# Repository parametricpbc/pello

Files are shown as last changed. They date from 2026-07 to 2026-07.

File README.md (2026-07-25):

# Pello — Parametric's open-source GELLO leader arms

Open-source bimanual [GELLO](https://wuphilipp.github.io/gello_site/) teleoperation leader
arms, purpose-built to drive **[i2rt YAM](https://github.com/i2rt-robotics) follower arms**.
Each leader is a **5/8-scale replica of the 6-DOF YAM** (plus a gripper trigger), sensed by
**7× Feetech STS3215 serial-bus servos per arm**. You move the lightweight leaders by hand
and the YAM followers mirror your motion in real time via
[LeRobot](https://github.com/huggingface/lerobot).

> **Designed for the 6-DOF YAM**, not the 5-DOF SO-100. The software happens to drive the
> YAM through LeRobot's SO-100 follower interface, but the arm geometry and joint count are
> the YAM's.

<!-- TODO(preliminary): add a hero photo / short GIF of the arms in use -->

## What's in this repo

| Path | Contents |
|---|---|
| [`hardware/`](hardware/) | Bill of materials, 3D-print file, and assembly instructions |
| [`Uarm_teleop/Feetech_servo/`](Uarm_teleop/Feetech_servo/) | Servo GUI, bus scanner, and ID-assignment tools |
| [`Follower_Arm/LeRobot/`](Follower_Arm/LeRobot/) | Drive an i2rt YAM follower from the leaders via LeRobot |

## Build a set

1. **Order the parts** — [`hardware/BOM.md`](hardware/BOM.md) (~$389 for a bimanual set, 14 servos).
2. **Print the frame** — [`hardware/print/gello3dp.3mf`](hardware/print/gello3dp.3mf) (one arm on each plate).
3. **Assemble** — follow [`hardware/README.md`](hardware/README.md).
4. **Bring up the software** — below.

## Quick start (software)

**1. Install dependencies**

```bash
pip install -r requirements.txt
```

**2. Set your serial ports.** Each USB adapter enumerates differently per machine:

```bash
ls /dev/cu.usbmodem*   # macOS
ls /dev/ttyUSB*        # Linux
```

Update the port strings in `Uarm_teleop/Feetech_servo/feetech_gui.py` (top of file) and
`Follower_Arm/LeRobot/so100/dual_uarm_yam_teleop.py`.

**3. Assign servo IDs** (fresh servos all ship with the same default ID). With **one servo
connected to the bus at a time**, assign each an ID from **0 (base) to 6 (gripper/trigger)**:

```bash
cd Uarm_teleop/Feetech_servo
python3 feetech_servo_changeid.py 0   # then 1, 2, … 6, one servo at a time
```

The write broadcasts to every powered servo on the bus, so isolate each servo before
setting its ID. Once all 7 are set, wire the full daisy chain.

**4. Launch the servo GUI** (live 3D monitor — start here to verify a new build):

```bash
python3 feetech_gui.py
```

It opens `feetech_gui.html` in your browser, auto-discovers the servos, auto-zeros on the
first frame, and renders both arms in 3D. Press **H** to re-zero to the current pose. You
can also confirm the bus with `python3 feetech_scan.py`.

**5. Drive the YAM followers** (bimanual — each arm driven through LeRobot's SO-100 follower
interface):

```bash
cd ../../Follower_Arm/LeRobot/so100
python3 dual_uarm_yam_teleop.py
```

See [`Follower_Arm/LeRobot/README.md`](Follower_Arm/LeRobot/README.md) for the LeRobot setup.

## Hardware notes

- **Passive by design:** the two internal reduction gears are removed from each servo during
  assembly, so the joints are freely back-drivable. The servos sense position; they don't
  drive the arm (there is no active gravity compensation).
- **Servo IDs:** 0–6 per arm, stored in each servo's EEPROM. Re-assign with
  `Uarm_teleop/Feetech_servo/feetech_servo_changeid.py`.
- **Zero calibration:** captured live at startup — put the arms in their home pose before
  starting, or press **H** in the GUI to re-zero.

## Credits & license

Licensed under the **Apache License 2.0** — see [`LICENSE`](LICENSE) and [`NOTICE`](NOTICE).
This project is derived from
[MINT-SJTU/LeRobot-Anything-U-Arm](https://github.com/MINT-SJTU/LeRobot-Anything-U-Arm)
(please cite [arXiv:2509.02437](https://arxiv.org/abs/2509.02437)) and builds on the
[GELLO](https://github.com/wuphilipp/gello_mechanical) leader-arm concept (Wu et al.).

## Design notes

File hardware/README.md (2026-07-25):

# Hardware

Everything needed to build a set of Pello leader arms: bill of materials, the 3D-print
file, and assembly instructions. A set is **2 arms**, each with **7× Feetech STS3215**
servos (14 total) arranged as linkages **L1–L5** plus a **handle**, **trigger**, and
**base**.

## Bill of materials

See [`BOM.md`](BOM.md) — real parts, quantities, and prices (~$389 for a bimanual set).
The dominant cost is the 14 servos, ordered as two 6-packs plus one 2-pack.

## 3D printing

Print [`print/gello3dp.3mf`](print/gello3dp.3mf) — the master print file, one arm's parts
per plate (two plates for a bimanual set). Printed in **PETG**. This covers all structural
parts: base, L1–L5 linkages, handle, trigger, and hardstops.

Individual part STLs are in [`print/stl/`](print/stl/) (`Base`, `Home`, `L1`–`L5`, and
left/right `Handle` + `Trigger`) if you'd rather arrange your own plates or remix a
single part.

## Assembly

> The full illustrated step-by-step — with photos for every group — is in
> **[`ASSEMBLY.md`](assembly/ASSEMBLY.md)**. The outline below is a summary and follows
> that SOP's numbering. Recommend an electric screwdriver; two screw sizes are referred to
> as **BIG** and **SMALL**.

- **Step 0 — Prep the servos (×7 per arm).** Open each servo, remove the two internal
  reduction gears (this decouples the motor from the drive shaft so the joint is freely back-drivable), reassemble, and mount both servo horns (toothed + non-toothed).
- **Step 1 — Build the four sub-assemblies:** Group 1 (L1–L3), Group 2 (L4–L5), Group 3
  (handle + trigger), Group 4 (base + driver board).
- **Step 2 — Join the groups** into a full arm, then press-fit the assembly into the base (do this after
  wiring for easier cable routing).
- **Step 3 — Wire** the servos as a daisy chain terminating at the driver board, then connect
  the board to the host over USB-C.
- **Step 4 — Verify** in software: power the board, assign servo IDs, and confirm
  the bus (see bring-up below).

## Electronics & bring-up

- **Power:** ~7.4V @ 5A external DC to the servo driver board.
- **Host:** USB-C from the board to your computer.
- **Assign servo IDs first** — fresh servos all ship with the same default ID. Assign each
  an ID from **0 (base) to 6 (gripper/trigger)** with
  [`../Uarm_teleop/Feetech_servo/feetech_servo_changeid.py`](../Uarm_teleop/Feetech_servo/feetech_servo_changeid.py),
  isolating one servo on the bus at a time (the write broadcasts to every powered servo).
- **Verify the bus** — once all 7 are set and the chain is wired, run
  [`feetech_gui.py`](../Uarm_teleop/Feetech_servo/feetech_gui.py) or
  [`feetech_scan.py`](../Uarm_teleop/Feetech_servo/feetech_scan.py) and confirm IDs 0–6 all
  respond with none on the factory default.

> **Tip — steady the leaders while driving.** You move the arms by hand, so anchor each base
> so it doesn't shift mid-motion: clamp it to your table edge (a small spring or bar clamp
> works well), or even to a chair armrest for a seated teleop setup.

Full software setup is in the [top-level README](../README.md).

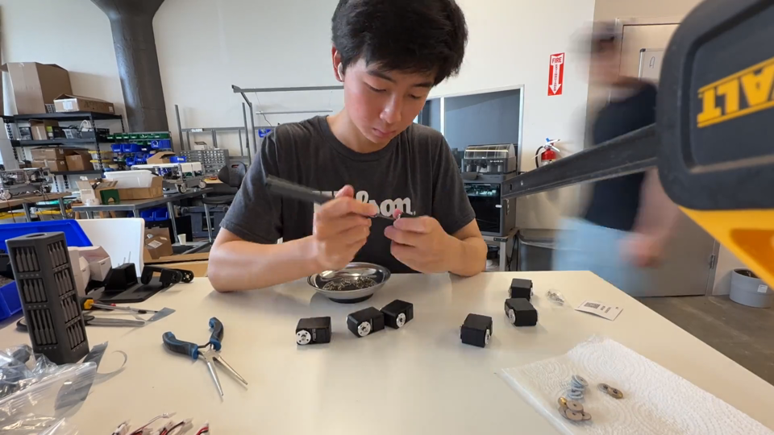
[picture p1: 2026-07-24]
hardware/assembly/img/video-poster.png

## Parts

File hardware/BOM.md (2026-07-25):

# GELLO — Bill of Materials

Everything needed to build **one set of leaders (2 arms)**: a 5/8-scale i2rt YAM
replica with **7× Feetech STS3215 servos per arm (14 total)** and a GELLO-style
gripper handle.

Prices are in USD (parts as of July 2026). The 14 servos are ordered as **two 6-packs
plus one 2-pack** — cheaper and more reliable than buying singles.

## Purchased parts

| # | Component | Qty | Price |
|---|---|----:|---:|
| 1 | [Feetech STS3215 servo — 6-pack](https://www.amazon.com/dp/B0FQHCV9GP) | 2 packs (12 servos) | $269.98 |
| 2 | [Feetech STS3215 servo — 2-pack](https://www.amazon.com/STS3215-Serial-Magnetic-Programmable-Robotic/dp/B0FVS63YNN) | 1 pack (2 servos) | $45.98 |
| 3 | [Serial bus servo driver board — Waveshare, 2-pack](https://www.amazon.com/dp/B0DK79JNNK) | 1 pack (2 boards) | $19.99 |
| 4 | [Power supply — SHNITPWR 60W universal adjustable](https://www.amazon.com/SHNITPWR-Universal-Adjustable-100V-240V-Converter/dp/B08BL55LMB) | 2 power supplies | $37.98 |
| | **Total (one leader set / 2 arms)** | | **$373.93** |

> **Not included in the total:** the **3D-printed parts** (~800 g PETG, ~$14 in filament —
> print your own or use a service; see [`print/`](print/)) and the **shared consumables**
> below.

**Servo count:** 14 total = 2 arms × 7 servos (IDs 0–6 per arm). Two 6-packs + one 2-pack =
14, with zero spare. A single-arm build needs 7 servos (one 6-pack + one 2-pack).

## Also required (not in the total)

Commodity items needed to build and run a set, but left out of the cost above.

### Consumables

Used up or installed into the build.

| Item | Qty | For |
|---|-----|-----|
| Super glue | 1 | Gluing the hardstop home onto M1 (Step 2); optionally mounting the board (see below). |
| Heat-set inserts — M2.5 | 8 (4 per arm) | Mounting the driver board to the base. The board ships with its mounting screws preinstalled, so no extra bolts are needed. |
| Rubber band — sturdy ~[#32](https://www.amazon.com/Alliance-26324-Advantage-Contains-Approx/dp/B00A27PFOC) | 2 (1 per arm) | Trigger return spring. Only a couple needed per set. |

> **No soldering iron?** You can skip the heat-set inserts entirely and **glue the
> driver board onto the back of the base** instead, mounting it the same way shown in the
> assembly reference photos. See [`ASSEMBLY.md`](assembly/ASSEMBLY.md) (Step 1, Group 4).

### Tools & other items

Reusable — not consumed and not part of the finished arm.

| Item | Qty | For |
|---|-----|-----|
| Philips screwdriver (electric recommended) | 1 | Driving all the BIG/SMALL screws; also pushing wires into the servo sockets. |
| Pliers | 1 | Freeing the servo top plates in Step 0. |
| Soldering iron | 1 | Installing the M2.5 heat-set inserts — **only if** you use inserts; skip it if you glue the board on instead. |
| USB-C cable | 2 (1 per arm) | Driver board → host computer. Any data-capable cable. |

<!-- Provenance: internal GELLO BOM (Notion) 3a6b7cb7-364f-8033-8293-d405878abf79 -->

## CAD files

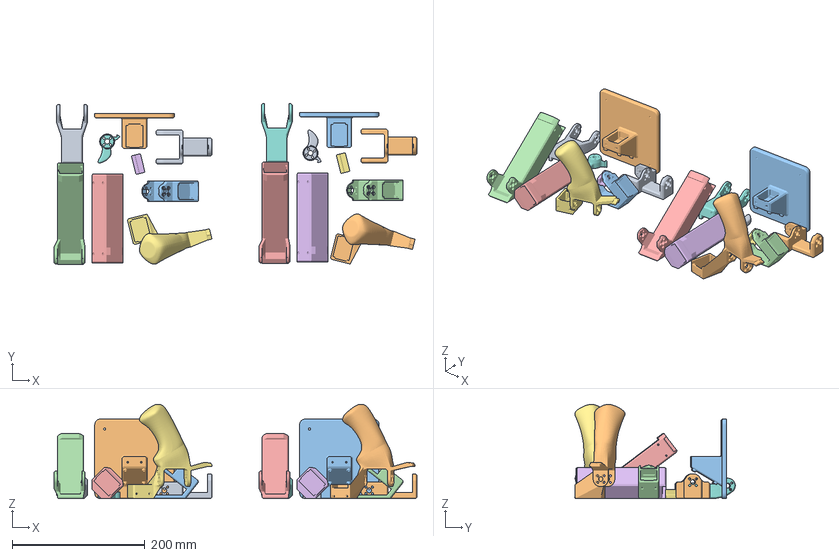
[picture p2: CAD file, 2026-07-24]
hardware/print/gello3dp.3mf
547.0 x 242.1 x 142.1 mm
L1 (1).stl x 2
Base (1).stl x 2
Current L5 (1).stl x 2
L3.stl x 2
L2 3D Model.stl x 2
Hardstop Home (4).stl x 2
Hardstop Handle (12).stl
Trigger (1).stl
Current L4 (1).stl x 2
Trigger (2).stl
Hardstop Handle (13).stl

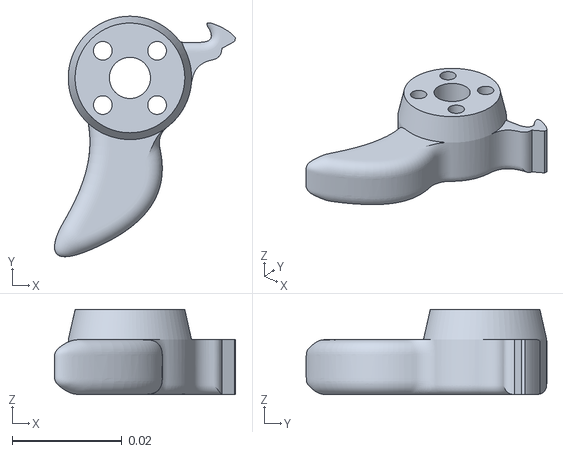
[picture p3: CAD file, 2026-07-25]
hardware/print/stl/RH Trigger.stl
0.033 x 0.0439 x 0.0155

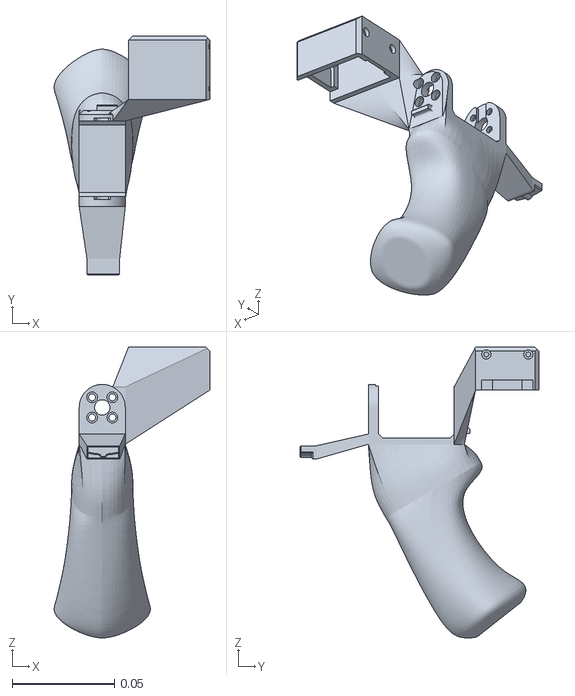
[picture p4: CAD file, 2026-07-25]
hardware/print/stl/LH Handle.stl
0.0762 x 0.117 x 0.142

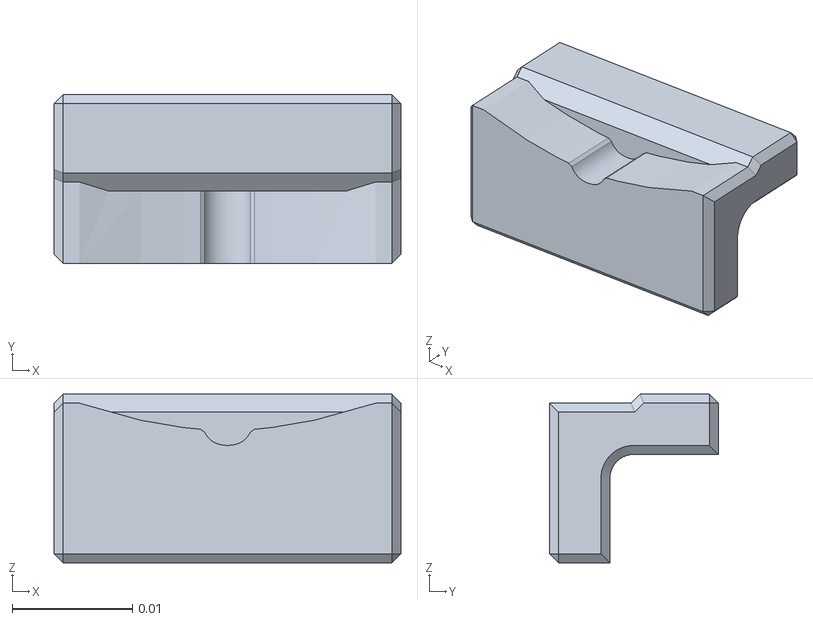
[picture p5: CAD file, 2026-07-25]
hardware/print/stl/Home.stl
0.0288 x 0.014 x 0.014

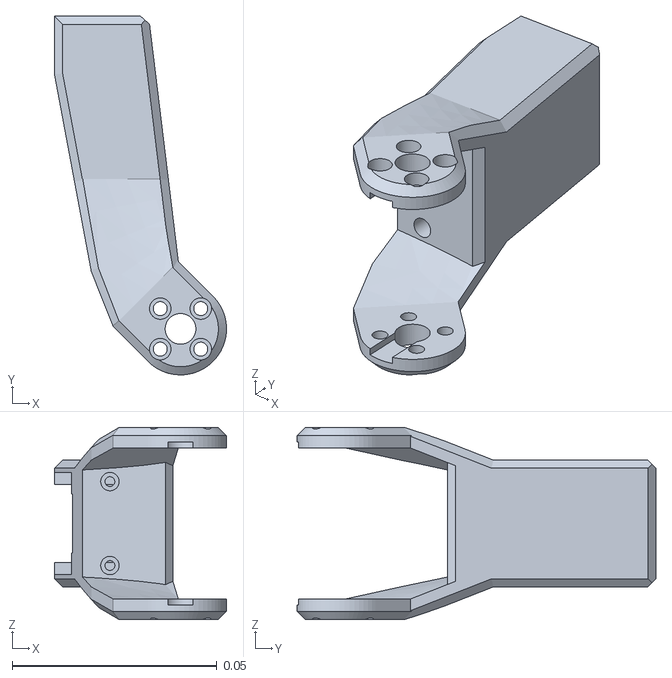
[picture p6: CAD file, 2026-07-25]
hardware/print/stl/L4.stl
0.042 x 0.0876 x 0.0469

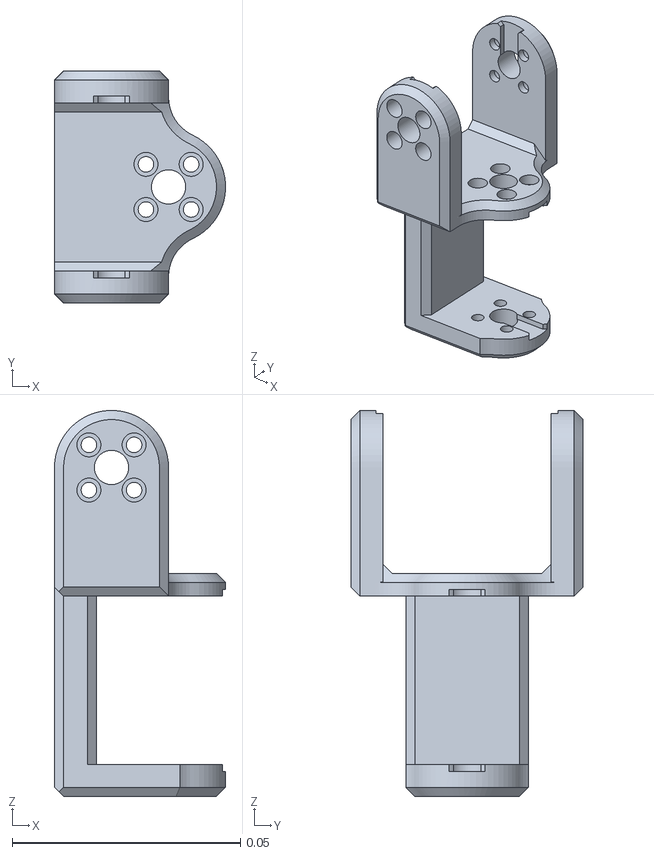
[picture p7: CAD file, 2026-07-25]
hardware/print/stl/L1.stl
0.0375 x 0.0509 x 0.0846

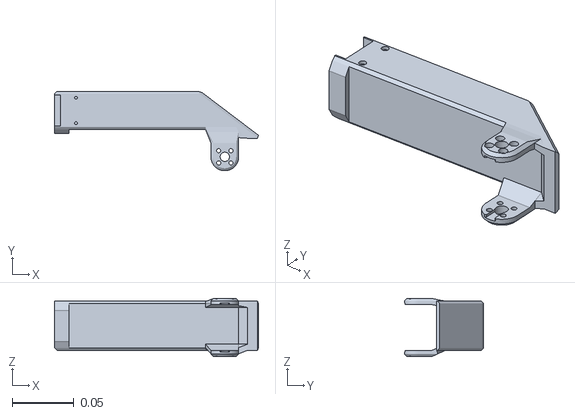
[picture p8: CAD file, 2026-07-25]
hardware/print/stl/L3.stl
0.165 x 0.0642 x 0.0469

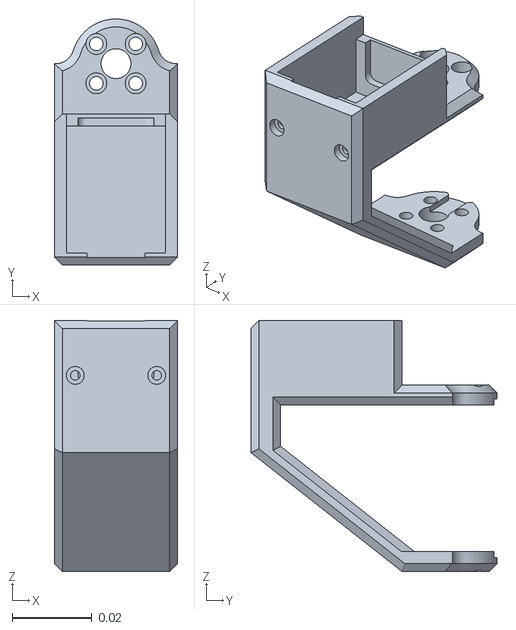
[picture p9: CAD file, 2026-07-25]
hardware/print/stl/L5.stl
0.031 x 0.0619 x 0.0632

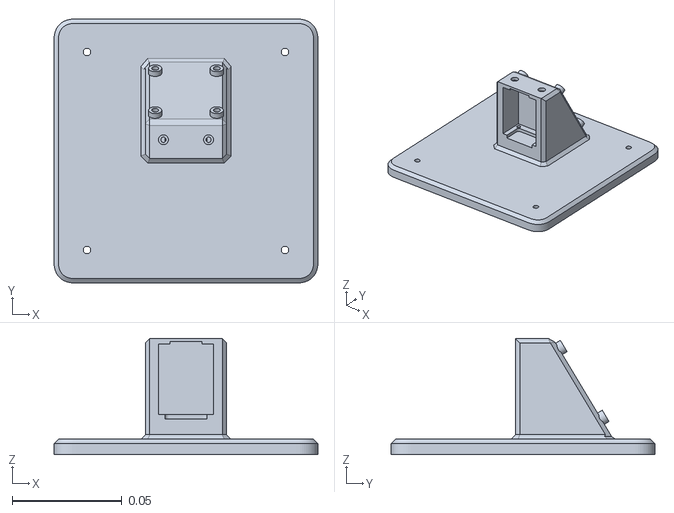
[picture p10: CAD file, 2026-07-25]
hardware/print/stl/Base.stl
0.12 x 0.12 x 0.0527

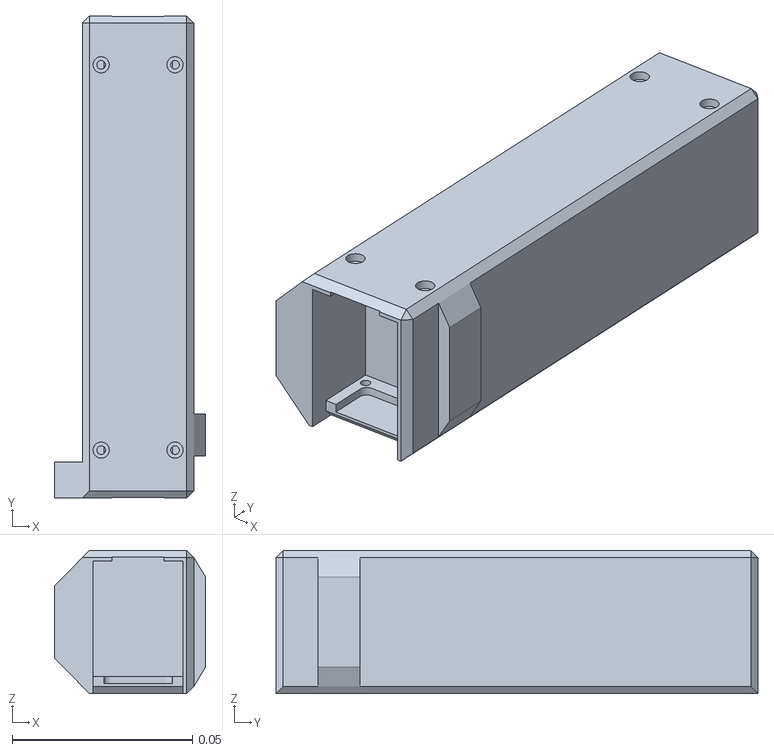
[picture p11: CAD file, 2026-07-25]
hardware/print/stl/L2.stl
0.042 x 0.134 x 0.0398

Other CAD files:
hardware/print/stl/RH Handle.stl
hardware/print/stl/LH Trigger.stl

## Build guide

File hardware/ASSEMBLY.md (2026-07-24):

# GELLO Assembly Instructions

Assembly SOP for the Parametric GELLO leader arms. Apply each step to **every one of the 7
servos / for each arm** you're building. An electric screwdriver is recommended. Two screw
sizes are referenced throughout as **BIG** and **SMALL** (both take the Philips bit).

## Video

https://github.com/user-attachments/assets/be1396df-c70d-4008-bce5-4e55a3319c4a

## Reference files

- **3D-print file:** [`gello3dp.3mf`](gello3dp.3mf)
- **Bill of materials:** [`BOM.md`](BOM.md)

## Overview

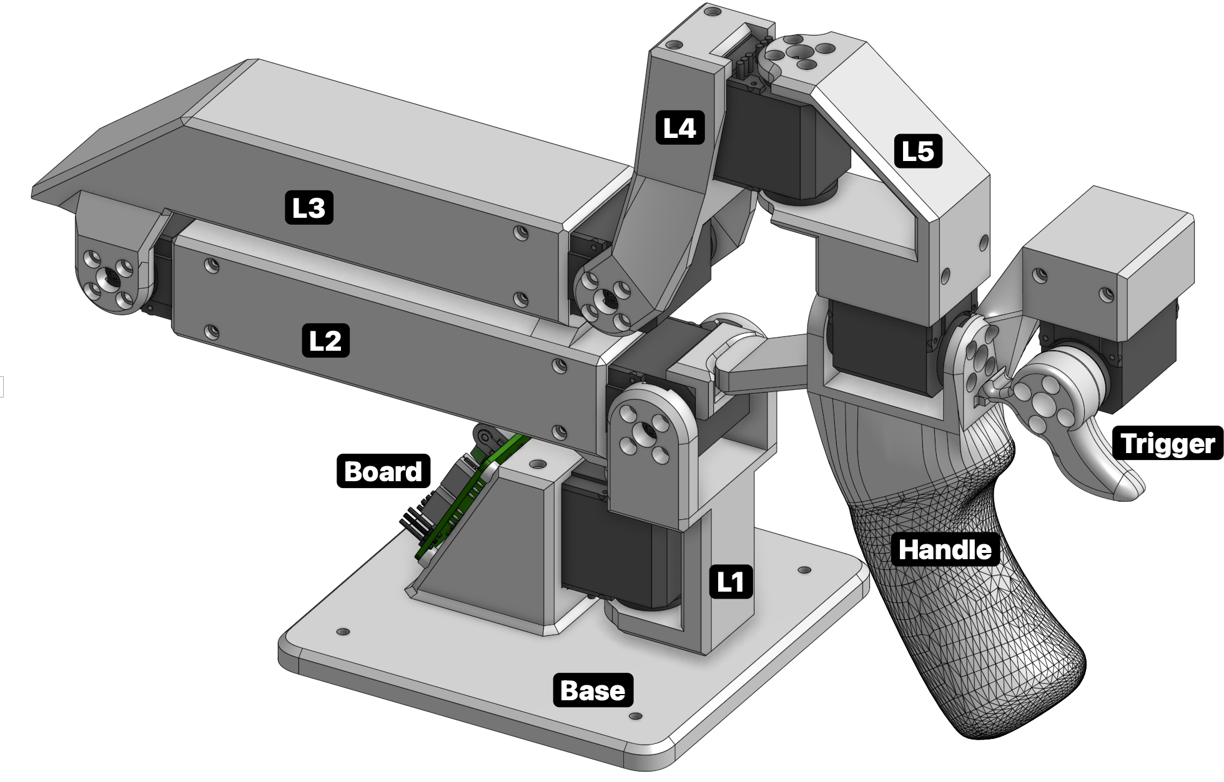
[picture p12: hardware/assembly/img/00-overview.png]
Assembly overview


Each arm builds up as four sub-assemblies:

| Group | Parts | |
|---|---|---|
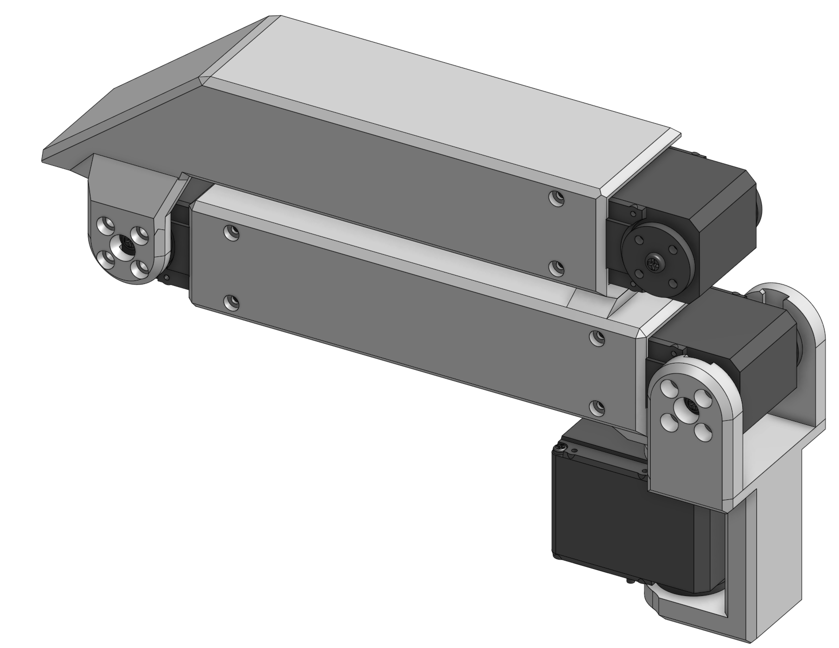
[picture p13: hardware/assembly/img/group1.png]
Group 1
| **Group 1** | L1, L2, L3 |  |
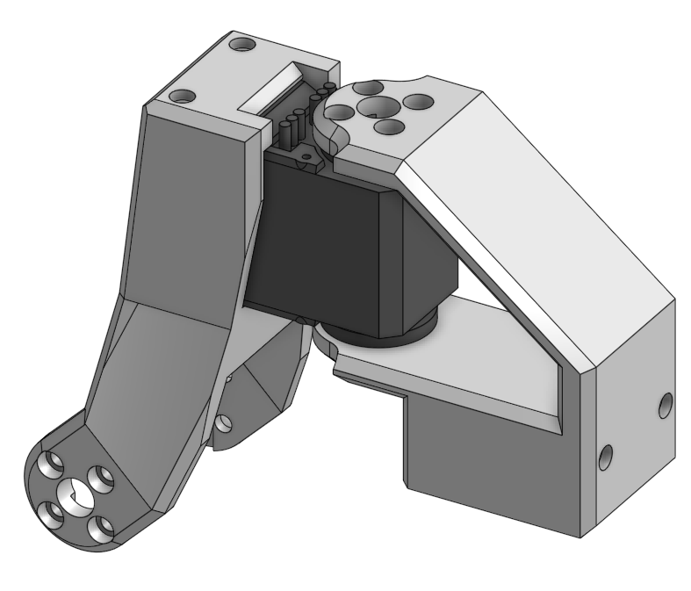
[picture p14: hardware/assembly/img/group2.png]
Group 2
| **Group 2** | L4, L5 |  |
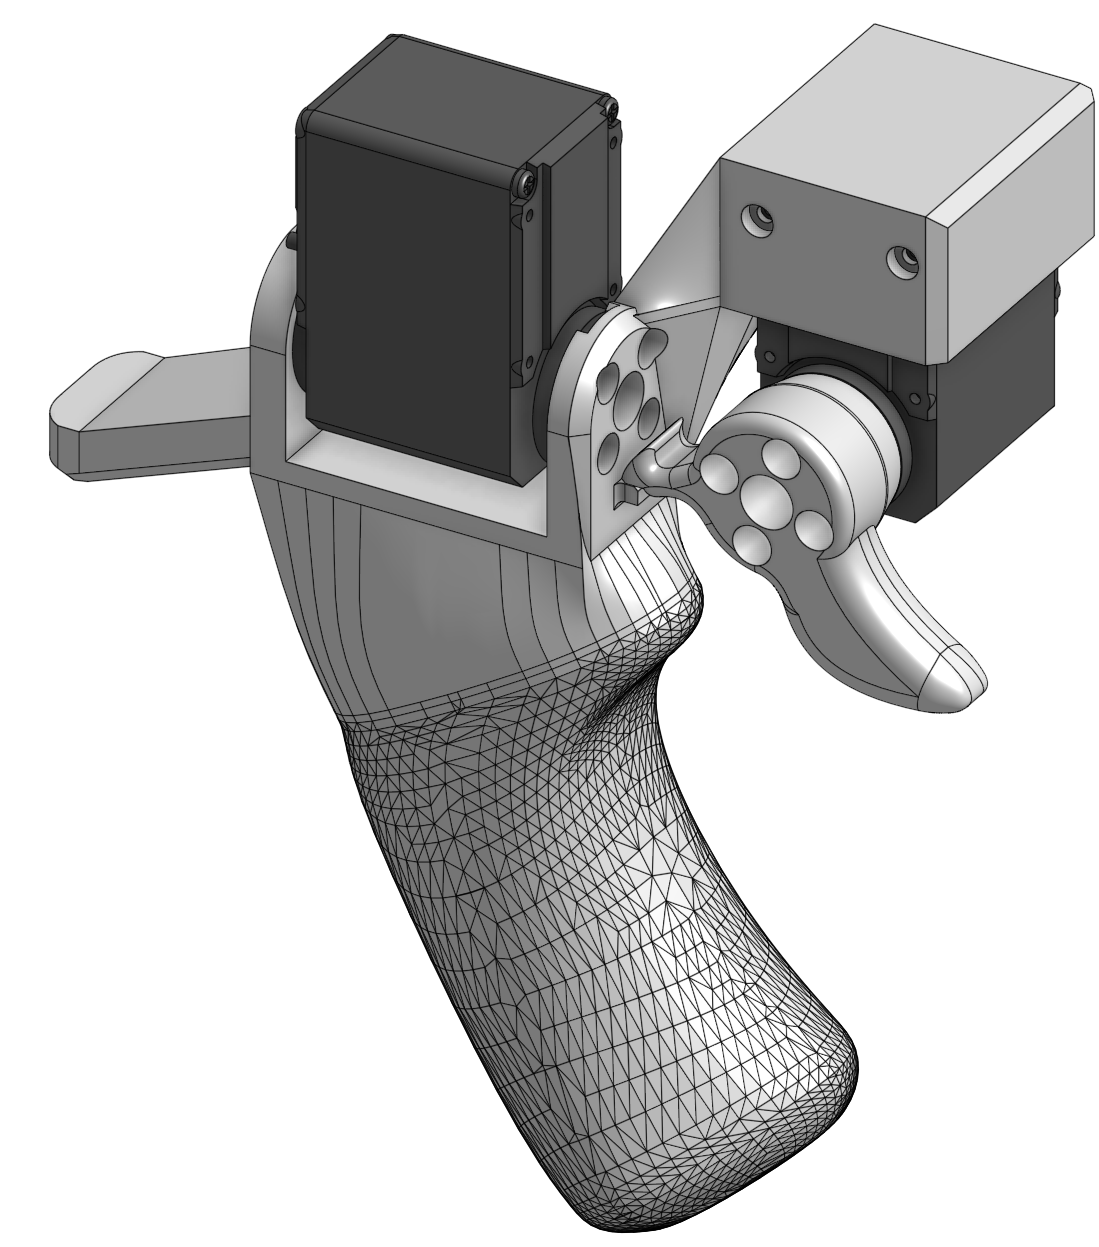
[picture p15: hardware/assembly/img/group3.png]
Group 3
| **Group 3** | handle, trigger |  |
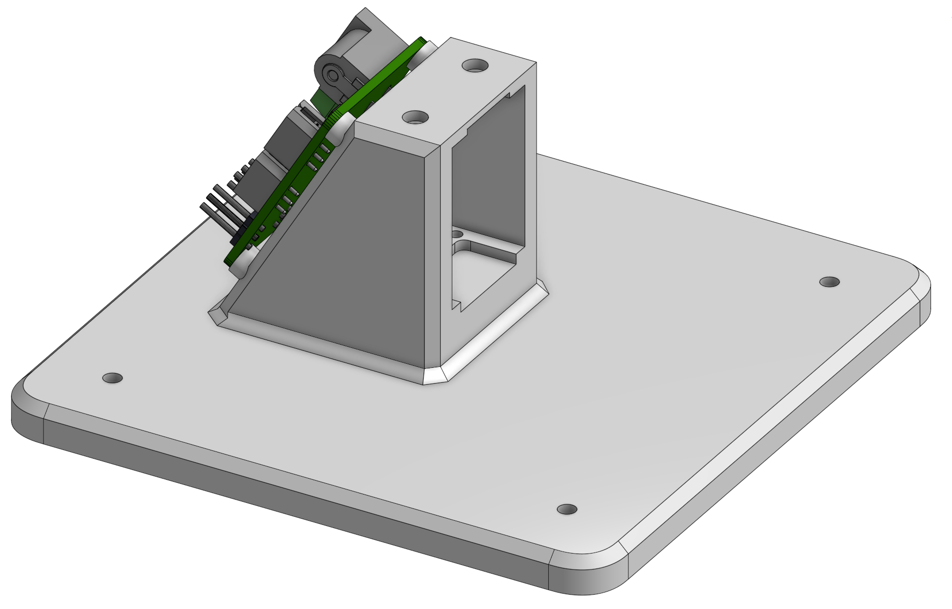
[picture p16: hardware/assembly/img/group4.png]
Group 4
| **Group 4** | base + board |  |

## Step 0 — Prepare the servos (×7 per arm)

- Ensure you have 7 Feetech STS3215 servos per arm, including the required accessories
  (mounting screws + metal servo horns).

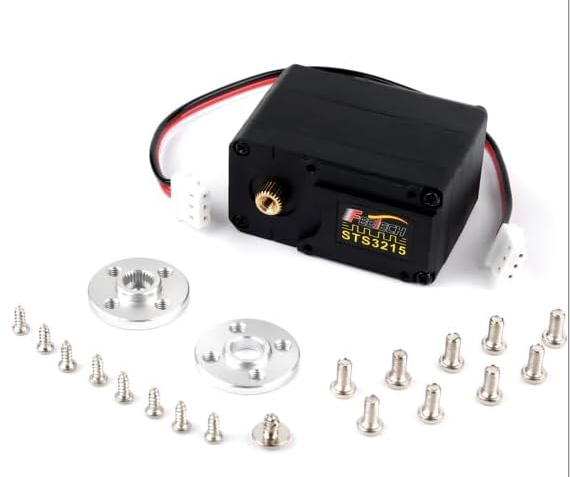
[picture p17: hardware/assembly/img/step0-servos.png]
Servos and accessories
  

- Using a Philips screwdriver, remove the 4 screws that secure the servo's top plate (use
  pliers if needed to free the plate).
  - Keep track of which cover came off which servo, and return each cover to its own servo —
    mismatched covers may not fit back together perfectly.

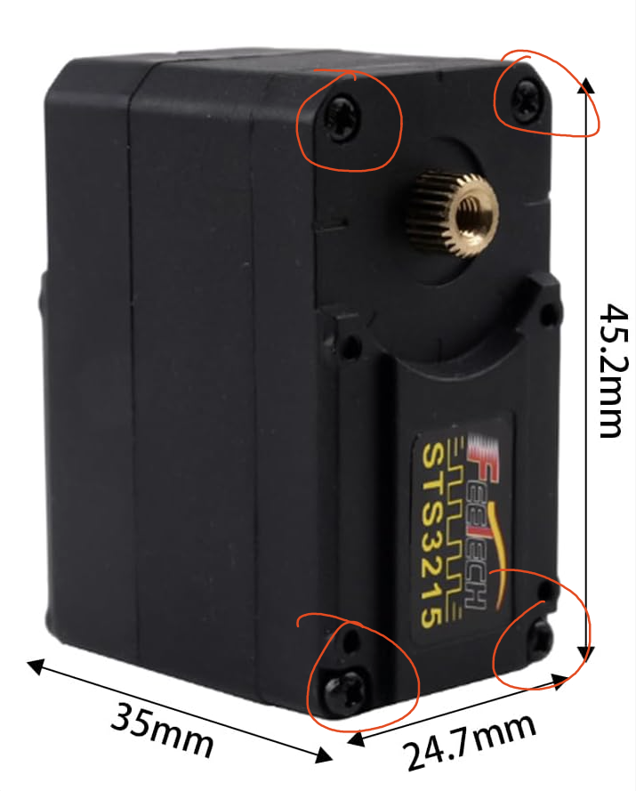
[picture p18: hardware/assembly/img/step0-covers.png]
Removing the servo cover
  

- Remove the two interior gears from the servo. This decouples the motor from the output
  shaft so the joint is **freely back-drivable** — the core GELLO principle.
  - Place the gears on a paper towel and store them as spares (in the GELLO box).
  - The interior is lubricated, so work carefully to avoid a mess.

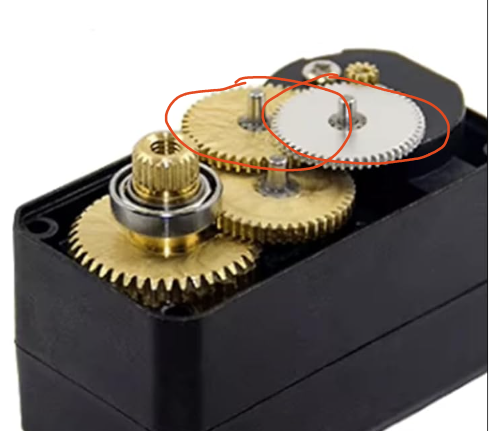
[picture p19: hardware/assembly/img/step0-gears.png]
Interior gears to remove
  

- Replace the cover and screw the four Philips screws back in.
- Identify the 2 servo horns per motor (toothed + non-toothed):
  - Mount the **toothed** horn on the toothed end of the servo — teeth lined up, pushed on
    firmly until flush, secured with a BIG screw.

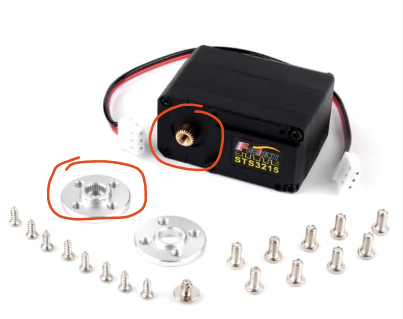
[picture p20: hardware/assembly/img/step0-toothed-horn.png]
Mounting the toothed horn
    

  - Mount the **non-toothed** horn on the opposite side, ring facing the servo, pushed on
    flush. Secure with the screw that has the washer (1 per motor); some resistance is
    normal.

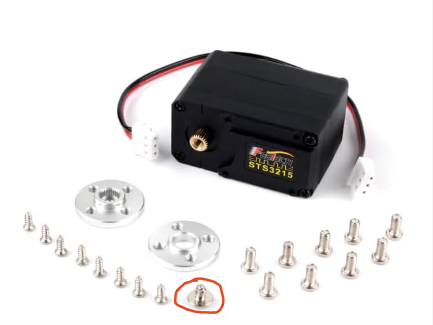
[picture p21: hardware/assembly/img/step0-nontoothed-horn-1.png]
Non-toothed horn
    
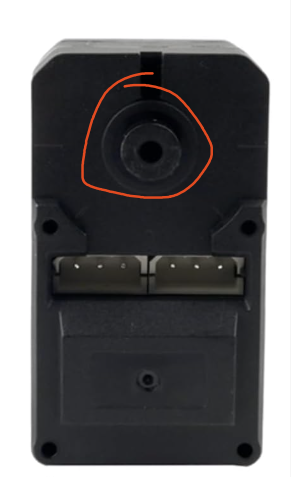
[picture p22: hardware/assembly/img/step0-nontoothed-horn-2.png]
Non-toothed horn seated
    

## Step 1 — Assemble each group

**Notes before you start:**
- Linkages don't need all screws — ~2 per side is adequate.
- Press-fit acceptances are orientation-dependent (they fit one way); inner guide mounts are
  omnidirectional. Keep all wire connectors pointing the direction the steps specify, or
  you'll have to redo steps.
- If you get lost, fall back on the reference images above and below.

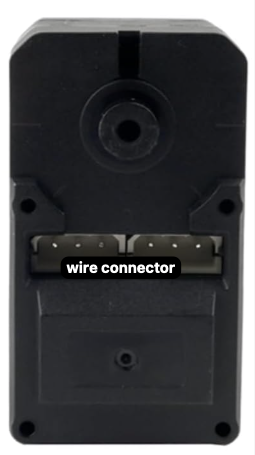
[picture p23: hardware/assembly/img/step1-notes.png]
Assembly notes reference


### Group 1 (L1, L2, L3)

Group 1

- Press-fit servos into either end of L2; secure each side with SMALL screws.
- Press-fit a servo into the straight end of L3; secure each side with SMALL screws.
- Using L3's inner guides (all wire connectors pointing the same direction), slide L3 onto
  the end of L2 that has no hardstops (the plain rectangular extrusion); secure each side
  with BIG screws.

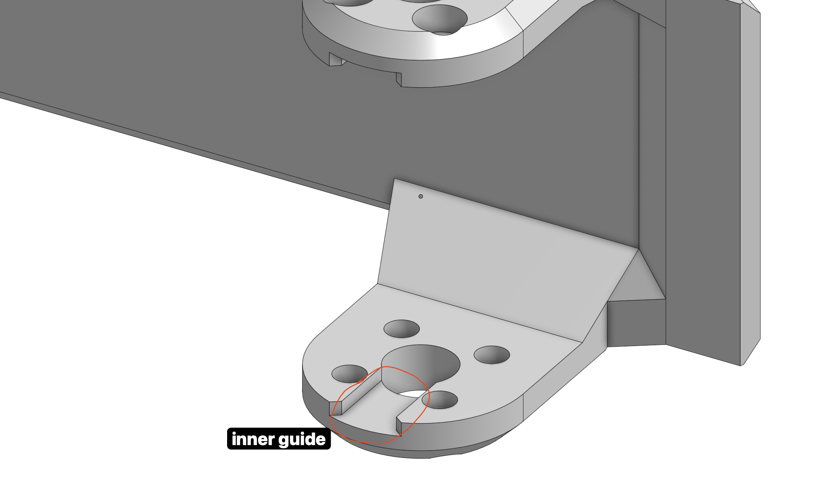
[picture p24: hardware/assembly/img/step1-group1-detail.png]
Group 1 detail
  

- Slide a servo into the bottom of L1 (this connects to the base) with the wire connector
  pointing down into the base, away from the rest of the assembly; secure each side with BIG
  screws.
- Slide L2's open end onto the top of L1; secure each side with BIG screws, ensuring L2
  extends back along the length of L1's servo.

### Group 2 (L4, L5)

Group 2

- Press-fit a servo into L4; secure each side with SMALL screws.
- Slide L5 onto the servo; secure with BIG screws, with its press-fit acceptance pointing
  opposite the wire connector.

### Group 3 (handle, trigger)

Group 3

- Slide a servo into the top of the handle, wire connectors pointing away from where the
  trigger installs; secure each side with BIG screws.
- Press-fit a servo into the trigger mount on the handle; secure each side with SMALL screws.
- Secure the trigger to the press-fit servo with BIG screws.
- Double-wrap a rubber band around the handle and slide it up to just below the bump; loop
  one of the two loops around the trigger. Confirm the trigger returns to its home hardstop
  and stops against the bump at the other limit.

### Group 4 (base + board)

Group 4

- Heat-set M3×4×5 inserts into the back of the base (where the board mounts) so they sit
  flush with the 4 rings.
- Secure the board to the base with four 6–8 mm M3 bolts into the heat-set inserts.

## Step 2 — Connect the groups

**Group 3 → Group 2:** Press-fit the servo coming out of the handle (Group 3) up into the
open receiving end on L5 (Group 2); secure the open side with SMALL screws.

**Groups 2 + 3 → Group 1:** Slide Groups 2 and 3 onto the open servo on L3; secure each side
with BIG screws. Glue the hardstop home onto M1 — this is the female homing mechanism.

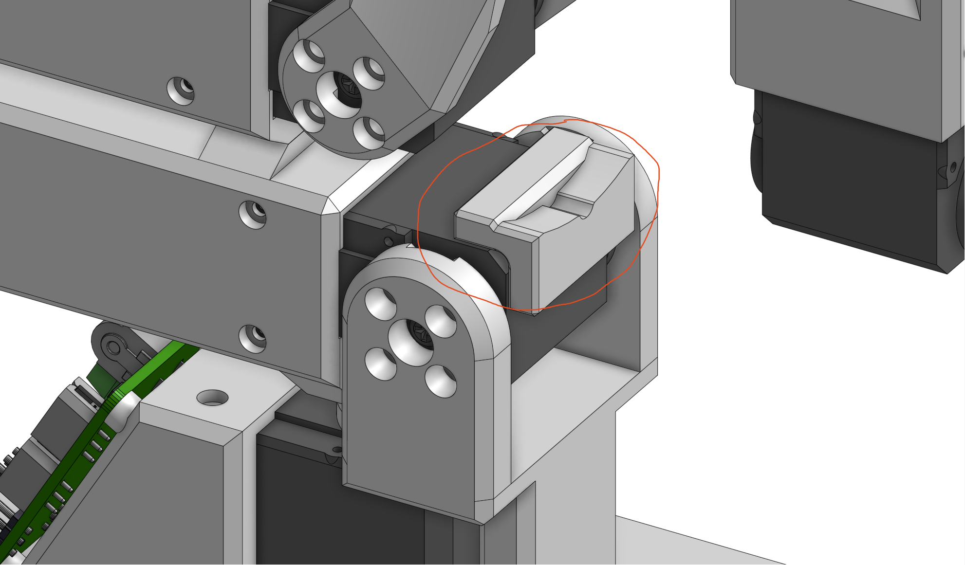
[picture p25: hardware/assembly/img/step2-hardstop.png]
Hardstop home glued onto M1


> **Do Step 3 (wiring) before attaching the base** — it's much easier to wire first.

**Groups 1 + 2 + 3 → base:** Press-fit the servo into the base; secure each side with SMALL
screws. Move the other linkages out of the way to make room.

## Step 3 — Wiring

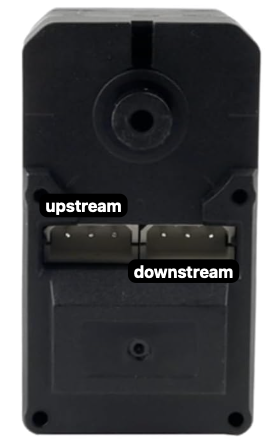
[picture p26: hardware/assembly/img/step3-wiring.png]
Wiring


- The servos are **daisy-chained** one to the next (e.g. trigger downstream → handle upstream
  → … ), and the chain terminates at the board.
- A screwdriver helps push the wires into the sockets; cables only fit one way.
- Connect the board to the host device via USB-C.
- Upstream/downstream order doesn't technically matter — this SOP fixes an order only for
  consistency between GELLOs.

## Step 4 — Verification

See the [top-level README](../README.md) for full software bring-up.

- Power the board from an external DC source (~7.4V @ 5A) and connect it to the host via USB-C.
- **Assign each servo an ID** with
  [`feetech_servo_changeid.py`](../Uarm_teleop/Feetech_servo/feetech_servo_changeid.py) — the
  servos are all daisy-chained, so:
  - Fresh servos ship with the same default ID; assign IDs *before* wiring the full chain if
    possible.
  - Fully disconnect a servo from its neighbors before setting its ID — nothing plugged into
    either of its two ports except the single cable to the board (either port works; both are
    electrically identical).
    - This isn't only about duplicate factory defaults: the write **broadcasts to every
      powered servo on the bus**, so a servo you already assigned will be overwritten if it's
      still on the chain.
  - Index IDs from **0 (base) to 6 (gripper/trigger)**, matching each servo's position in the
    chain.
  - Set `SERIAL_PORT` at the top of the script to your board's port (mac: `ls /dev/cu.*`;
    linux: `/dev/ttyUSB0`).
  - Run `python feetech_servo_changeid.py <id>` and confirm it prints `Succeed to set id: <id>`.
  - Label each servo with its ID before moving to the next, so they don't get mixed up.
  - Once all 7 are set, wire the full chain and use
    [`feetech_gui.py`](../Uarm_teleop/Feetech_servo/feetech_gui.py) (or
    [`feetech_scan.py`](../Uarm_teleop/Feetech_servo/feetech_scan.py)) to confirm IDs 0–6 all
    respond and none are still on the factory default.
  - If reusing a servo pulled from another arm, double-check its old ID first — it can collide
    with the new chain.

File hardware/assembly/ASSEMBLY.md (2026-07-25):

# GELLO Assembly Instructions

Assembly SOP for the Parametric GELLO leader arms. Apply each step to **every one of the 7
servos / for each arm** you're building. An electric screwdriver is recommended. Two screw
sizes are referenced throughout as **BIG** and **SMALL** (both take the Philips bit).

## Video

https://github.com/user-attachments/assets/be1396df-c70d-4008-bce5-4e55a3319c4a

## Reference files

- **3D-print file:** [`gello3dp.3mf`](../print/gello3dp.3mf)
- **Bill of materials:** [`BOM.md`](../BOM.md)

## Overview

Assembly overview

Each arm builds up as four sub-assemblies:

| Group | Parts | |
|---|---|---|
| **Group 1** | L1, L2, L3 | Group 1 |
| **Group 2** | L4, L5 | Group 2 |
| **Group 3** | handle, trigger | Group 3 |
| **Group 4** | base + board | Group 4 |

## Step 0 — Prepare the servos (×7 per arm)

- Ensure you have 7 Feetech STS3215 servos per arm, including the required accessories
  (mounting screws + metal servo horns).

  Servos and accessories

- Using a Philips screwdriver, remove the 4 screws that secure the servo's top plate (use
  pliers if needed to free the plate).
  - Keep track of which cover came off which servo, and return each cover to its own servo —
    mismatched covers may not fit back together perfectly.

  Removing the servo cover

- Remove the two interior gears from the servo. This decouples the motor from the output
  shaft so the joint is **freely back-drivable** — the core GELLO principle.
  - Place the gears on a paper towel and store them as spares (in the GELLO box).
  - The interior is lubricated, so work carefully to avoid a mess.

  Interior gears to remove

- Replace the cover and screw the four Philips screws back in.
- Identify the 2 servo horns per motor (toothed + non-toothed):
  - Mount the **toothed** horn on the toothed end of the servo — teeth lined up, pushed on
    firmly until flush, secured with a BIG screw.

    Mounting the toothed horn

  - Mount the **non-toothed** horn on the opposite side, ring facing the servo, pushed on
    flush. Secure with the screw that has the washer (1 per motor); some resistance is
    normal.

    Non-toothed horn
    Non-toothed horn seated

## Step 1 — Assemble each group

**Notes before you start:**
- Linkages don't need all screws — ~2 per side is adequate.
- Press-fit acceptances are orientation-dependent (they fit one way); inner guide mounts are
  omnidirectional. Keep all wire connectors pointing the direction the steps specify, or
  you'll have to redo steps.
- If you get lost, fall back on the reference images above and below.

Assembly notes reference

### Group 1 (L1, L2, L3)

Group 1

- Press-fit servos into either end of L2; secure each side with SMALL screws.
- Press-fit a servo into the straight end of L3; secure each side with SMALL screws.
- Using L3's inner guides (all wire connectors pointing the same direction), slide L3 onto
  the end of L2 that has no hardstops (the plain rectangular extrusion); secure each side
  with BIG screws.

  Group 1 detail

- Slide a servo into the bottom of L1 (this connects to the base) with the wire connector
  pointing down into the base, away from the rest of the assembly; secure each side with BIG
  screws.
- Slide L2's open end onto the top of L1; secure each side with BIG screws, ensuring L2
  extends back along the length of L1's servo.

### Group 2 (L4, L5)

Group 2

- Press-fit a servo into L4; secure each side with SMALL screws.
- Slide L5 onto the servo; secure with BIG screws, with its press-fit acceptance pointing
  opposite the wire connector.

### Group 3 (handle, trigger)

Group 3

- Slide a servo into the top of the handle, wire connectors pointing away from where the
  trigger installs; secure each side with BIG screws.
- Press-fit a servo into the trigger mount on the handle; secure each side with SMALL screws.
- Secure the trigger to the press-fit servo with BIG screws.
- Double-wrap a rubber band around the handle and slide it up to just below the bump; loop
  one of the two loops around the trigger. Confirm the trigger returns to its home hardstop
  and stops against the bump at the other limit.

### Group 4 (base + board)

Group 4

- Heat-set M2.5 inserts into the back of the base (where the board mounts) so they sit
  flush with the 4 rings.
- Secure the board with its four preinstalled mounting screws, threaded into the heat-set
  inserts (no extra bolts needed).

> **No soldering iron or heat-set inserts?** You can instead **glue the board directly onto
> the back of the base** — position it the same way shown in the reference photo above. This
> skips the inserts entirely; a dab of super glue on the mounting pads holds
> it fine.

## Step 2 — Connect the groups

**Group 3 → Group 2:** Press-fit the servo coming out of the handle (Group 3) up into the
open receiving end on L5 (Group 2); secure the open side with SMALL screws.

**Groups 2 + 3 → Group 1:** Slide Groups 2 and 3 onto the open servo on L3; secure each side
with BIG screws. Glue the hardstop home onto M1 — this is the female homing mechanism.

Hardstop home glued onto M1

> **Do Step 3 (wiring) before attaching the base** — it's much easier to wire first.

**Groups 1 + 2 + 3 → base:** Press-fit the servo into the base; secure each side with SMALL
screws. Move the other linkages out of the way to make room.

## Step 3 — Wiring

Wiring

- The servos are **daisy-chained** one to the next (e.g. trigger downstream → handle upstream
  → … ), and the chain terminates at the board.
- A screwdriver helps push the wires into the sockets; cables only fit one way.
- Connect the board to the host device via USB-C.
- Upstream/downstream order doesn't technically matter — this SOP fixes an order only for
  consistency between GELLOs.

## Step 4 — Verification

See the [top-level README](../../README.md) for full software bring-up.

- Power the board from an external DC source (~7.4V @ 5A) and connect it to the host via USB-C.
- **Assign each servo an ID** with
  [`feetech_servo_changeid.py`](../../Uarm_teleop/Feetech_servo/feetech_servo_changeid.py) — the
  servos are all daisy-chained, so:
  - Fresh servos ship with the same default ID; assign IDs *before* wiring the full chain if
    possible.
  - Fully disconnect a servo from its neighbors before setting its ID — nothing plugged into
    either of its two ports except the single cable to the board (either port works; both are
    electrically identical).
    - This isn't only about duplicate factory defaults: the write **broadcasts to every
      powered servo on the bus**, so a servo you already assigned will be overwritten if it's
      still on the chain.
  - Index IDs from **0 (base) to 6 (gripper/trigger)**, matching each servo's position in the
    chain.
  - Set `SERIAL_PORT` at the top of the script to your board's port (mac: `ls /dev/cu.*`;
    linux: `/dev/ttyUSB0`).
  - Run `python feetech_servo_changeid.py <id>` and confirm it prints `Succeed to set id: <id>`.
  - Label each servo with its ID before moving to the next, so they don't get mixed up.
  - Once all 7 are set, wire the full chain and use
    [`feetech_gui.py`](../../Uarm_teleop/Feetech_servo/feetech_gui.py) (or
    [`feetech_scan.py`](../../Uarm_teleop/Feetech_servo/feetech_scan.py)) to confirm IDs 0–6 all
    respond and none are still on the factory default.
  - If reusing a servo pulled from another arm, double-check its old ID first — it can collide
    with the new chain.

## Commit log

2026-07-24 hardware: add bill of materials ($389.15, 14 servos)
2026-07-24 hardware: add RIGHT+LEFT_GELLO.3mf print plate
    [RIGHT+LEFT_GELLO.3mf]
2026-07-24 Fix price of 3D-print filament in BOM
    Updated the price of 3D-print filament from $19.22 to $13.83.
2026-07-24 Clarify 3D-print filament quantity in BOM
    Updated the quantity description for 3D-print filament from '1 spool' to '~ 800g'.
2026-07-24 Add link to 3D-print filament in BOM
2026-07-24 Fix quantity for Feetech STS3215 servo in BOM
    Updated the BOM to reflect the correct quantity for the Feetech STS3215 servo.
2026-07-24 Fix link formatting for rubber bands entry in BOM
2026-07-24 Update README with clearer servo assembly steps
    Clarified instructions for servo assembly and wiring.
2026-07-24 Update wiring instructions in README
    Clarify instructions for connecting the driver board.
2026-07-24 docs: add GELLO assembly instructions with images and video
2026-07-24 hardware: replace right+left_gello with gello3dp
    [RIGHT+LEFT_GELLO.3mf, gello3dp.3mf]
2026-07-24 hardware: move assembly instructions into hardware/, fix video embed
2026-07-24 hardware: embed assembly video via GitHub asset URL
2026-07-24 Remove assembly video reference from ASSEMBLY.md
    Removed the assembly video section from the documentation.
2026-07-24 Remove fallback download link from ASSEMBLY.md
    Removed fallback download link for video clip.
2026-07-24 hardware: rename assembly video to gello_assembly.mov
2026-07-24 hardware: point assembly video embed at renamed gello_assembly asset
2026-07-24 Add software (servo_tools + lerobot) under software/, plus LICENSE/NOTICE/requirements
    Organize teleop code into software/servo_tools/ and software/lerobot/;
    update all doc references; add Apache-2.0 LICENSE, NOTICE, requirements.txt, .gitignore.
2026-07-24 Revert "Add software (servo_tools + lerobot) under software/, plus LICENSE/NOTICE/requirements"
    This reverts commit 5ca48d907ac331c42956bd33d2913f0ba5be7382.
2026-07-24 Revise quantities and total in BOM table
    Updated quantities and total price in BOM for clarity.
2026-07-25 Adjust price for SHNITPWR power supply
    Updated the price of the SHNITPWR power supply in the BOM.
2026-07-25 hardware: add print/ folder with STLs + master 3mf; nest ASSEMBLY.md in assembly/; move video into img/
    [Base.stl, Home.stl, L1.stl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]
2026-07-25 hardware(BOM): split priced parts from shared consumables; add USB-C cables, glue, heat-set inserts + bolts, rubber bands; note glue-instead-of-inserts board mount
2026-07-25 hardware: correct heat-set inserts to M2.5, drop extra bolts (board uses servo screws), simplify super glue wording
2026-07-25 Revise BOM quantities and descriptions
    Updated quantities for rubber bands and clarified the description for heat-set inserts.
2026-07-25 hardware(BOM): add Tools section (screwdriver, pliers, soldering iron)
2026-07-25 hardware: board mounts with its preinstalled screws (not servo screws); add Tools section
2026-07-25 hardware: split not-in-cost items into Consumables + Tools & other items; add clamp-down operation tip to hardware README
